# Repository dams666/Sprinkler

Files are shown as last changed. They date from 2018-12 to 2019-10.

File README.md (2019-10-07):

# Sprinkler
Sprinkler est un projet open source d'arrosage intelligent pour son jardin d'intérieur.

Fonctionnalités:
- controle plusieurs vannes
- possède des capteurs d'humidité
- statistiques de consommation d'eau
- détection d'anomalies de fonctionnement (fuites, consommation d'eau excessive...)

Le hardware est disponible sur EADYEDA:
https://easyeda.com/Dams666/sprinkler

Voici la liste des composants (non exhaustive):

http://www.aliexpress.com/item/Free-shipping-6PCS-new-Plastic-electromagnetic-valve-24VDC-12VDC-solenoid-valve-for-drink-water-air-Quick/32402224149.html

http://www.ebay.fr/cln/deofr18/sprinkler/260672069015

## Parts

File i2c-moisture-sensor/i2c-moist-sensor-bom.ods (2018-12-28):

ID | Designator | Value | Qty | FarnellID | Manufacturer | Mfg # | Replacement options
1 | IC1 | Attiny441 | 1 | 2396717 | ATMEL | ATTINY441-SSU | Exact part as specified
2 | D1, D2 | RB521S30T1G | 2 | 2322476 | FAIRCHILD SEMICONDUCTOR | BAT54XV2 | Exact part as specified
3 | TH1 | NCP18XH103F03RB | 1 | 2456122 | MURATA | NCP18XH103F03RB | Exact part as specified
4 | R1 | 10k | 1 | 2379939 | PANASONIC ELECTRONIC COMPONENTS | ERJ3RBD1002V | Any 10k resistor
5 | R2 | 10k 0.5% | 1 | 2379939 | PANASONIC ELECTRONIC COMPONENTS | ERJ3RBD1002V | Exact part as specified
6 | X1 | 16MHz | 1 | 2395958 | MULTICOMP | MCRSD16000F183000RR | Exact part as specified
7 | C1, C2 | 33pF | 2 | 2310585 | MULTICOMP | MC0603N330J500CT | Any 33pF capacitor
8 | R4, R9 | 330R | 2 | 2446656 | MULTICOMP | MCWR06X3300FTL | Any 5% 330R resistor
9 | C3, C6 | 1u 10V | 2 | 2310637 | MULTICOMP | MC0603X105K100CT | Any 1u capacitor
10 | C4, C5 | 1n | 2 | 2310598 | MULTICOMP | MC0603B102K500CT | Any 1n capacitor
11 | R5, R6, R7, R8 | 1M | 4 | 2446602 | MULTICOMP | MCWR06X1004FTL | Any 1M resistor
12 | D3 | KP-1608SURCK | 1 | 2449786 | KINGBRIGHT | KP-1608SURCK | Any 2V Vf 0603 LED
13 | HEATSHRINK |  | 1 |  |  | CB-DWT16-4X/1M-BK

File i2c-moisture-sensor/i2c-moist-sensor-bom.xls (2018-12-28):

Ref | Qnty | Value |  |  | Footprint | Manufacturer | PartNo | Distributor | Comments
C1, C2, | 2 | 33p | 2 | 4 | Capacitors_SMD:C_0603 | MULTICOMP | MC0603N330J500CT | Farnell/2310585 | Can be replaced with 33p 50V capacitors
C3, C6, | 2 | 1u | 2 | 4 | Capacitors_SMD:C_0603 | MULTICOMP | MC0603X105K100CT | Farnell/2310637 | Can be replaced with 1u >=10V capacitors
C4, C5, | 2 | 1n | 2 | 4 | Capacitors_SMD:C_0603 | MULTICOMP | MC0603B102K500CT | Farnell/2310598 | Can be replaced with 1n 50V capacitors
D1, D2, | 2 | BAT54 | 2 | 4 | SMD_Packages:SOD-523 | FAIRCHILD SEMICONDUCTOR | BAT54XV2 | Farnell/2322476 | Exact as specified
D3, | 1 | LED | 2 | 2 | LEDs:LED-0603 | KINGBRIGHT | KP-1608SURCK | Farnell/2449786 | Exact as specified
IC1, | 1 | ATTINY441-SSU | 14 | 14 | Housings_SOIC:SOIC-14_3.9x8.7mm_Pitch1.27mm | ATMEL | ATTINY441-SSU | Farnell/2396717 | Exact as specified
P1, | 1 | CONN_02X03 | 0 | 0 | Pin_Headers:Pin_Header_Straight_2x03 |  |  |  | DNP
R1, | 1 | 10k | 2 | 2 | Resistors_SMD:R_0603 | PANASONIC ELECTRONIC COMPONENTS | ERJ3RBD1002V | Farnell/2379939 | Can be replaced with 10k resistor
R2, | 1 | 10k 0.1% | 2 | 2 | Resistors_SMD:R_0603 | PANASONIC ELECTRONIC COMPONENTS | ERJ3RBD1002V | Farnell/2379939 | Exact as specified
R4, R9, | 2 | 330 | 2 | 4 | Resistors_SMD:R_0603 | MULTICOMP | MCWR06X3300FTL | Farnell/2446656 | Can be replaced with 330R resistor
R5, R8, R7, R6, | 4 | 1M | 2 | 8 | Resistors_SMD:R_0603 | MULTICOMP | MCWR06X1004FTL | Farnell/2446602 | Can be replaced with 1M resistor
TH1, | 1 | NCP18XH103F03RB | 2 | 2 | Resistors_SMD:R_0603 | MURATA | NCP18XH103F03RB | Farnell/2456122 | Exact as specified
X1, | 1 | 16MHz | 2 | 2 | Crystals:Crystal_HC49-SD_SMD | MULTICOMP | MCRSD16000F183000RR | Farnell/2395958 | Exact as specified
 |  |  |  | 52
 |  |  |  | 1.56

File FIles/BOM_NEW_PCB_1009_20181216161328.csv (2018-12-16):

ID | Name | Designator | Footprint | Quantity | Manufacturer Part | Manufacturer | Supplier | Supplier Part | Mounted
1 | ATMEGA328P-PU | U1 | DIP-28_300MIL | 1 | ATMEGA328P-PU | MICROCHIP | LCSC | C33901 | Yes
2 | 10k | R2,R3,R4 | AXIAL-0.3 | 3 | ? |  |  |  | Yes
3 | 100nF | C1 | RAD-0.1 | 1 | ? |  |  |  | Yes
4 | 22pF | C2,C3 | RAD-0.1 | 2 | ? |  |  |  | Yes
5 | 16MHZ | X1 | OSC-49S-1 | 1 | X49SD16MSD2SC | EasyEDA | EasyEDA | C16212 | Yes
6 | 1N4148 | D2 | DO-35 | 1 | ? |  |  |  | Yes
7 | 5MM CONNECTOR | I2C-1,I2C-2,5V-2,5V-1,VALVE1,VALVE2,VALVEM,VALVE3 | 5MM CONNECTOR | 8 | 5MM CONNECTOR |  |  |  | Yes
8 | DS1307+ | U2 | DIP-8 | 1 | DS1307+ | MAXIM | LCSC | C59267 | Yes
9 | 820 | R1,R5 | AXIAL-0.3 | 2 | ? |  |  |  | Yes
10 | BD139 | Q1 | TO-126 | 1 | BD139 | STMicroelectronics | LCSC | C27866 | Yes
11 | 820k | R6,R7 | AXIAL-0.3 | 2 | ? |  |  |  | Yes
12 | WATER FLOW | U3 | CONNECTOR 3P 5MM_2 | 1 | New SchematicLib |  |  |  | Yes
13 | 2N3904 | Q2 | TO-92(TO-92-3) | 1 | 2N3904 | SEMTECH | LCSC | C118538 | Yes
14 | BS-2-1 | B2 | BATTERY-1 | 1 | BS-2-1 | Q&J | LCSC | C70376 | Yes
15 | Quartz 32,7 KHz | X2 | XTAL1X2 | 1 | ? |  |  |  | Yes
16 | CAPACITOR_ELECTROLITIC_470UF | C4 | CAPACITOR_ZLH_10X12.5 | 1 | ? |  |  |  | Yes
17 | TIP120 | Q3,Q5,Q6,Q4,Q7,Q8,Q9 | TO-220_VERTICAL | 7 | ? |  |  |  | Yes
18 | POWER | U4 | CONNECTOR 3P 5MM_2 | 1 | New SchematicLib |  |  |  | Yes
19 | 2.2k | R8,R9,R10,R11,R12,R13,R14 | AXIAL-0.3 | 7 | ? |  |  |  | Yes
20 | MOIST | U5 | CONNECTOR 3P 5MM_2 | 1 | New SchematicLib |  |  |  | Yes
21 | Connector 2.54 2 Pins | U6,U7 | CONNECTOR 2.54 2 PINS | 2 | New SchematicLib |  |  |  | Yes
22 | 5 MM CONNECTER | BUZZER | 5MM CONNECTOR | 1 | 5MM CONNECTOR |  |  |  | Yes
23 | SWITCH-MOMENTARY-2PTH_EZ | S1 | TACTILE-PTH-EZ | 1 | ? |  |  |  | Yes

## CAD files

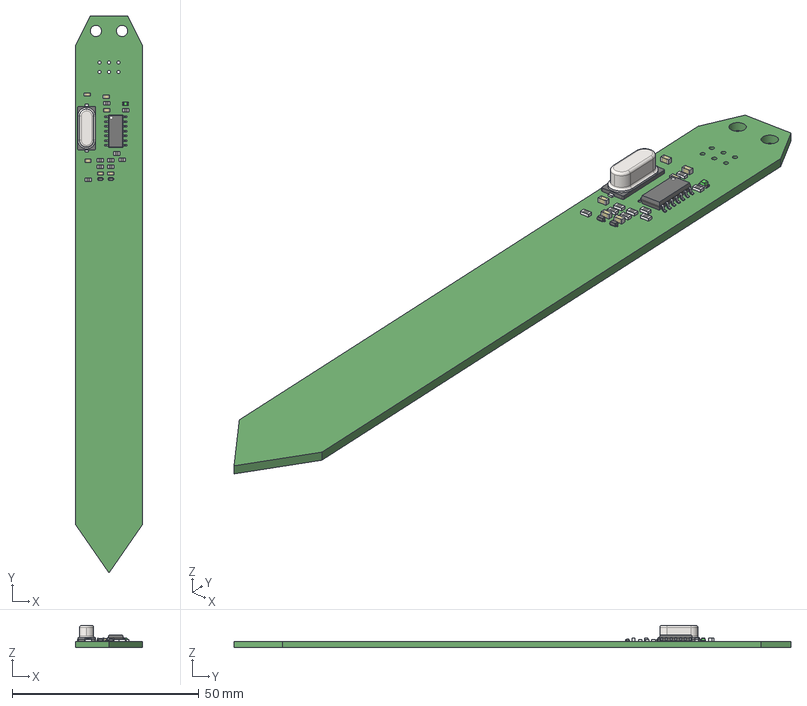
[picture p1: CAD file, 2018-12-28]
i2c-moisture-sensor/i2c-moist-sensor.stp
18.0 x 149.0 x 5.90 mm

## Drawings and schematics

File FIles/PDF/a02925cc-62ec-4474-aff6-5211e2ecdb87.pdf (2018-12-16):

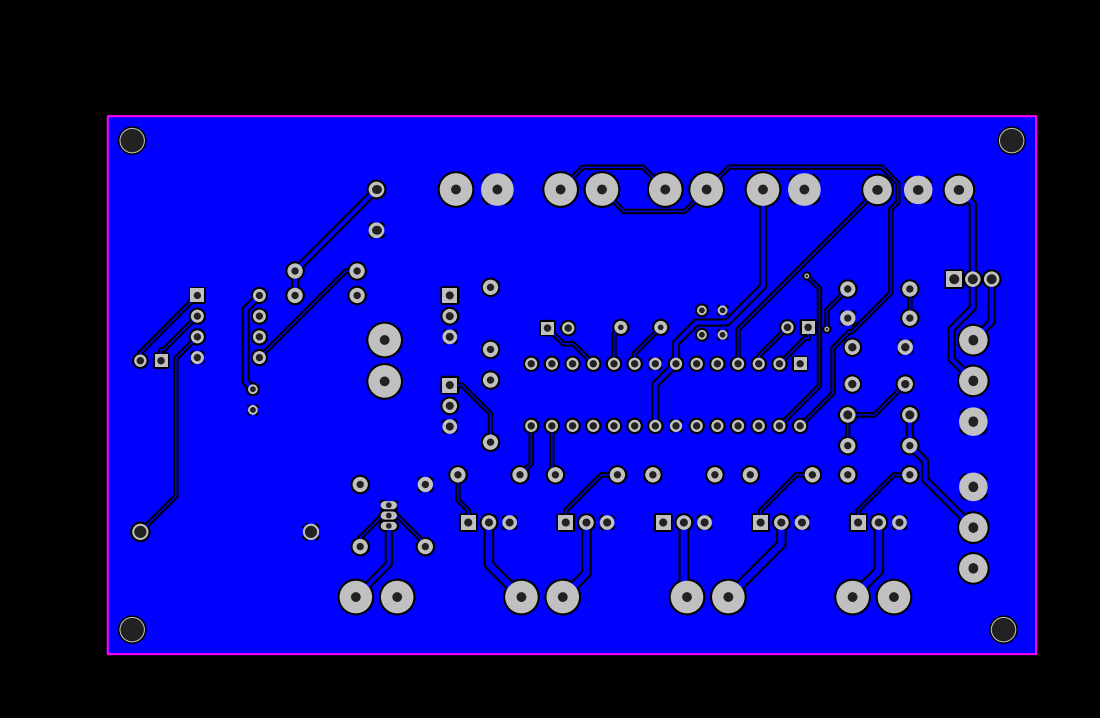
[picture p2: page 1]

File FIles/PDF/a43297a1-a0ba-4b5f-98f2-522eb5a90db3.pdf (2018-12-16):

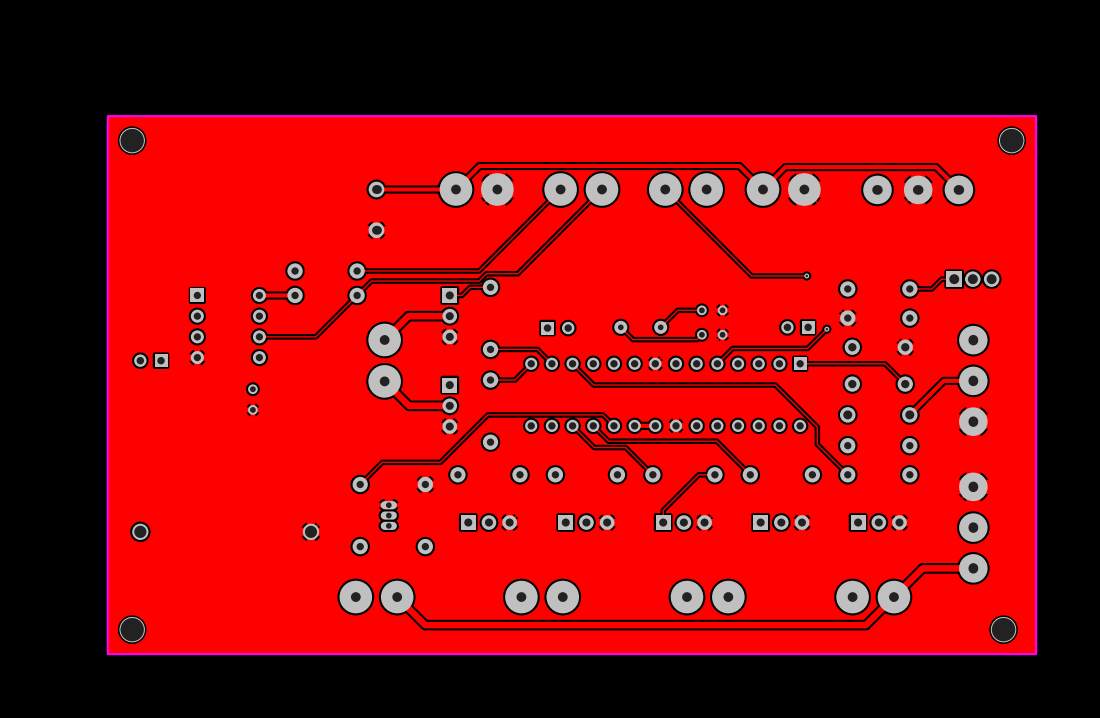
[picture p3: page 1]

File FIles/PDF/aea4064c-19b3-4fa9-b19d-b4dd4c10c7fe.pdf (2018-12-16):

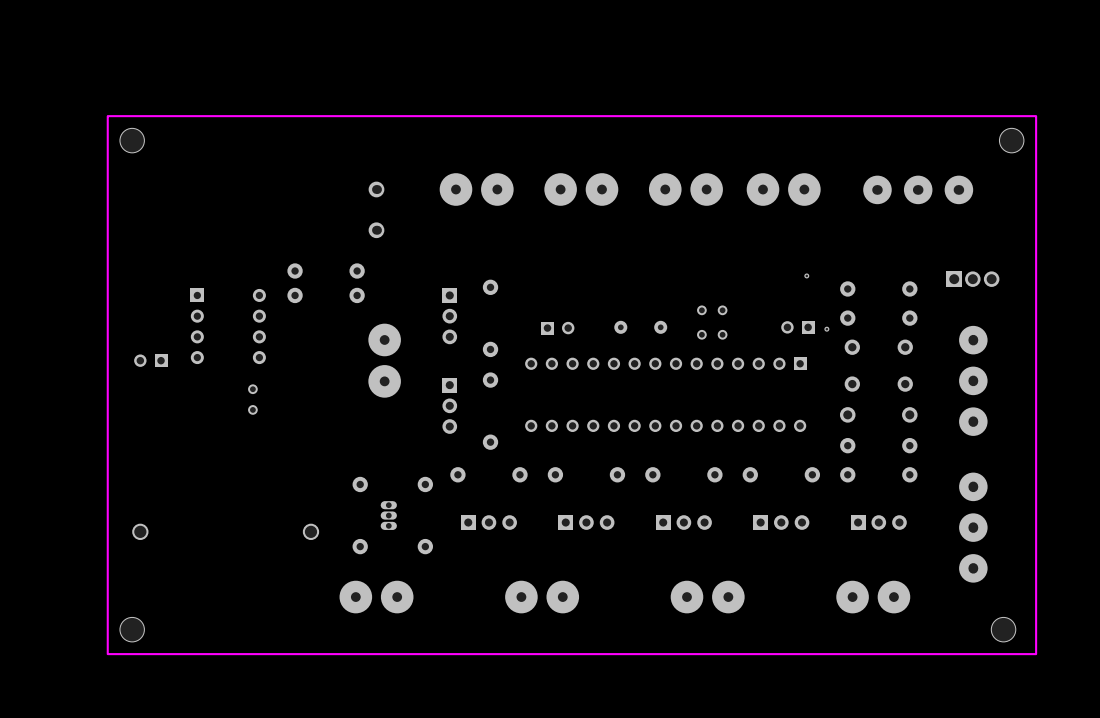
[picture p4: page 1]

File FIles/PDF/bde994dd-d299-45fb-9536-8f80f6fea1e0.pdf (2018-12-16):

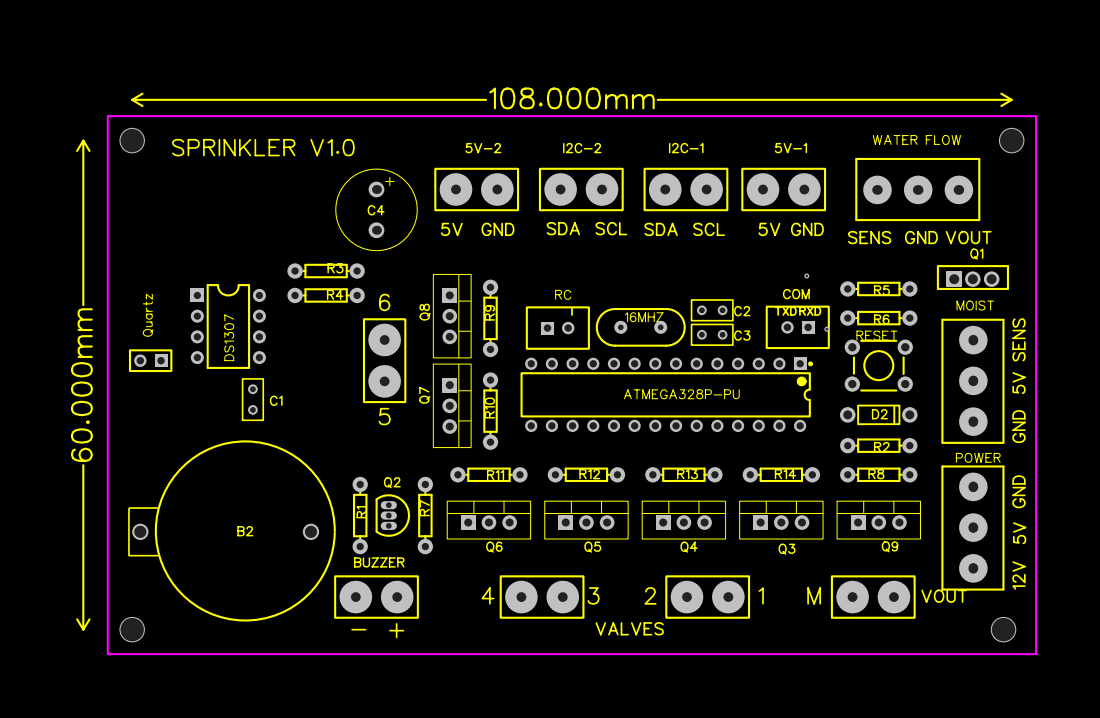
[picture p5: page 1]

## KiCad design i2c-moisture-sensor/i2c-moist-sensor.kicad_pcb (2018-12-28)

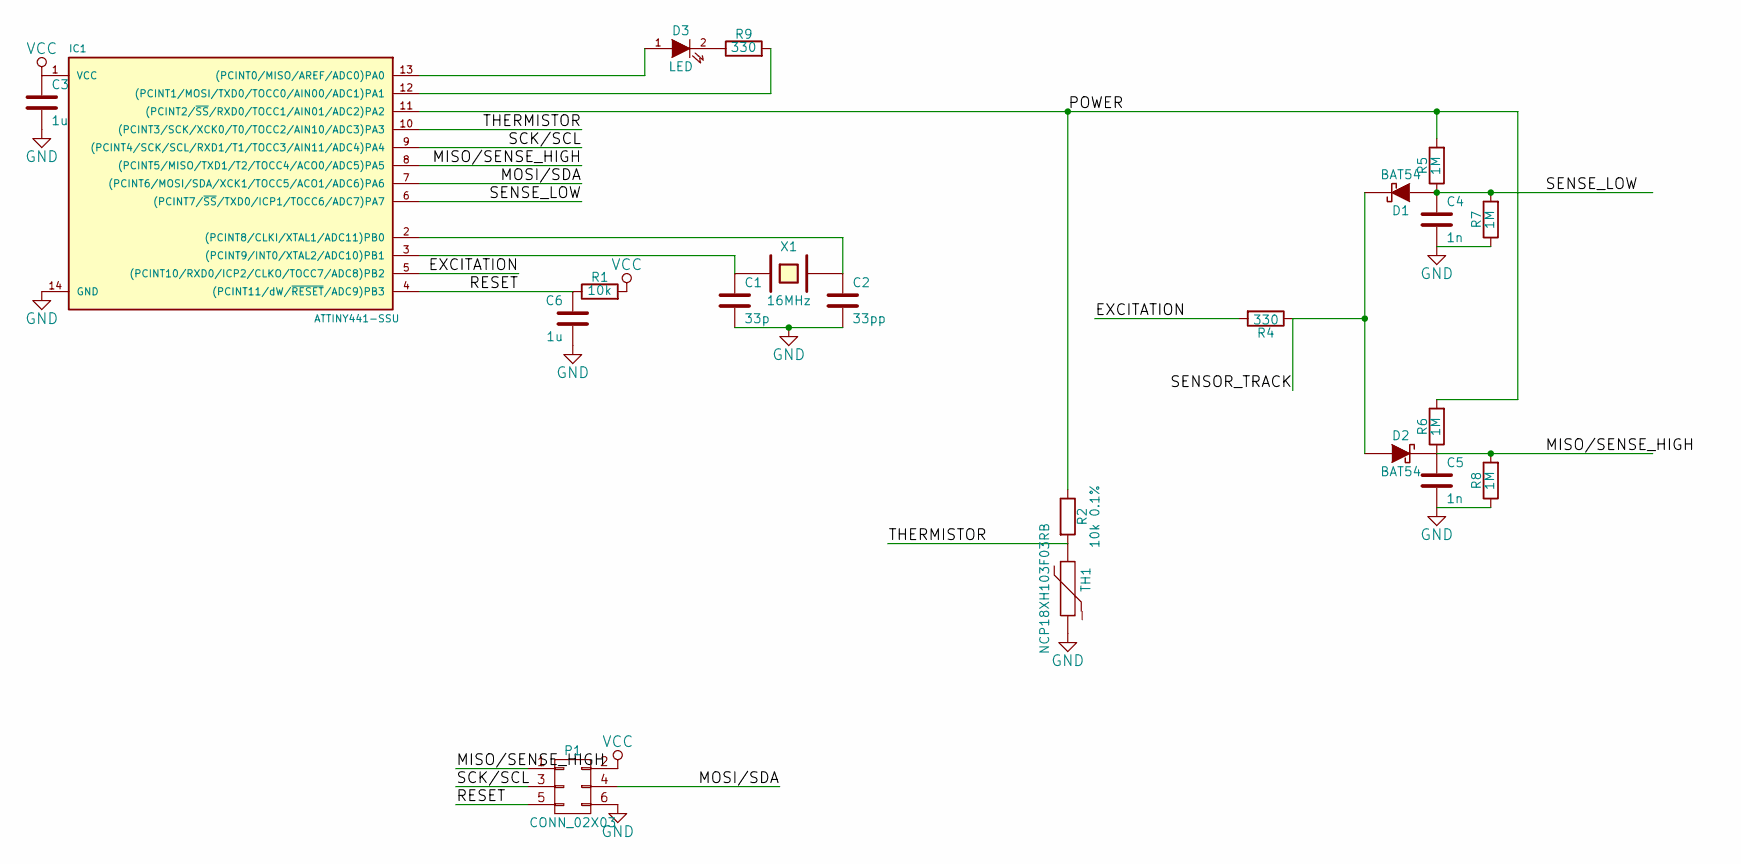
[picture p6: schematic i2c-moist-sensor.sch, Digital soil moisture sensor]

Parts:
C1: 33p; C_0603; PartNo MC0603N330J500CT
C2: 33pp; C_0603; PartNo MC0603N330J500CT
C3, C6: 1u; C_0603; PartNo MC0603X105K100CT
C4, C5: 1n; C_0603; PartNo MC0603B102K500CT
D1, D2: BAT54; SOD-523; PartNo BAT54XV2
D3: LED; LED-0603; PartNo KP-1608SURCK
IC1: ATTINY441-SSU; SOIC-14_3.9x8.7mm_Pitch1.27mm; PartNo ATTINY441-SSU
P1: CONN_02X03; Pin_Header_Straight_2x03
R1: 10k; R_0603; PartNo ERJ3RBD1002V
R2: 10k 0.1%; R_0603; PartNo ERJ3RBD1002V
R4, R9: 330; R_0603; PartNo MCWR06X3300FTL
R5, R6, R7, R8: 1M; R_0603; PartNo MCWR06X1004FTL
TH1: NCP18XH103F03RB; R_0603; PartNo NCP18XH103F03RB
X1: 16MHz; Crystal_HC49-SD_SMD; PartNo MCRSD16000F183000RR

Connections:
/EXCITATION: IC1.5 ((PCINT10/RXD0/ICP2/CLKO/TOCC7/ADC8)PB2), R4.2
/MISO/SENSE_HIGH: C5.1, D2.2 (K), IC1.8 ((PCINT5/MISO/TXD1/T2/TOCC4/ACO0/ADC5)PA5), P1.1, R6.1, R8.2
/MOSI/SDA: IC1.7 ((PCINT6/MOSI/SDA/XCK1/TOCC5/ACO1/ADC6)P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), P1.4
/RESET: C6.1, IC1.4 ((PCINT11/dW/~RESET~/ADC9)PB3), P1.5, R1.1
/SCK/SCL: IC1.9 ((PCINT4/SCK/SCL/RXD1/T1/TOCC3/AIN11/ADC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), P1.3
/SENSE_LOW: C4.1, D1.1 (A), IC1.6 ((PCINT7/~SS~/TXD0/ICP1/TOCC6/ADC7)PA7), R5.1, R7.2
/SENSOR_TRACK: D1.2 (K), D2.1 (A), R4.1
/THERMISTOR: IC1.10 ((PCINT3/SCK/XCK0/T0/TOCC2/AIN10/ADC3)PA3), R2.2, TH1.1
GND: C1.2, C2.2, C3.2, C4.2, C5.2, C6.2, IC1.14 (GND), P1.6, R7.1, R8.1, TH1.2
unnamed: C1.1, IC1.3 ((PCINT9/INT0/XTAL2/ADC10)PB1), X1.1
unnamed: C2.1, IC1.2 ((PCINT8/CLKI/XTAL1/ADC11)PB0), X1.2
unnamed: D3.1 (A), IC1.13 ((PCINT0/MISO/AREF/ADC0)PA0)
unnamed: D3.2 (K), R9.1
unnamed: IC1.11 ((PCINT2/~SS~/RXD0/TOCC1/AIN01/ADC2)PA2), R2.1, R5.2, R6.2
unnamed: IC1.12 ((PCINT1/MOSI/TXD0/TOCC0/AIN00/ADC1)PA1), R9.2
VCC: C3.1, IC1.1 (VCC), P1.2, R1.2

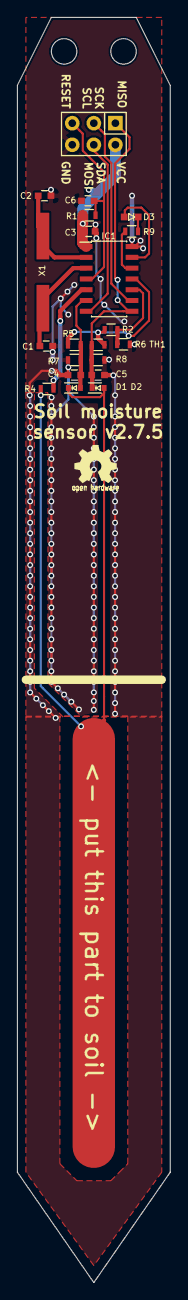
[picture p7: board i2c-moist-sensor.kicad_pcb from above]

Board: 2 copper layers, 18.0 x 149.0 mm, 21 parts (0 on the bottom side), 16 nets.

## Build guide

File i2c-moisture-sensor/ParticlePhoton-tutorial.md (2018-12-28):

Getting sensor to work with Particle Photon
===========================================
by Miriam Cox

As someone completely new to electrical work and to Particle microcontrollers, I hit a few slight hurdles in trying to convert this. For anyone else interested in how I got the sensor working with a Particle Photon, it's pretty simple:

**1) STARTING YOUR PROJECT**
Copy the example code into a "New App" in your Particle.io web IDE. You can name it whatever you'd like. Make sure you ALSO have your Particle Photon microcontroller registered to your Particle account so that you can flash the project onto it.

**2) ADDING A LIBRARY**
Create a new file inside this new app, then name it according to the library you are using (I eventually used Apollon77's code, as suggested by Miceuz) and copy the appropriate code from its git repo into these new files. Don't forget to include the library in your app's main file using the following syntax:
#include "NameOfLibraryFile.h"

_Note: As of this writing, it is also possible to fork this repo and rewrite it for import as a library into your Particle app, but that is a bit more work._

**3) INCLUDES**
In any library or example files you added to your project, strip out "define if/else" statements and their contents, then replace them with the following line (which will add Wire library and device functionality):
**#include "Particle.h"**

Flash your Photon with this app. Assuming you are successful (and assuming you also have the particle software installed on your computer) you can then open up a command line prompt on your computer and enter this command to view the serial monitor output from the Photon:
**particle serial monitor**

**4) SOLDERING**
For prototyping, I unplugged the Photon (which had headers), then popped it onto a breadboard. Then I stripped some jumper wires and soldered them directly to the I2C sensor's SCK/SCL line, VCC line, GND line, and SDA/MOSI line.

Obviously, you need to connect the Photon to your sensor; so to take advantage of the I2C capabilities of the Photon, you'll need to connect the Photon's D1 input to the sensor's SCK/SCL (clock) output, and then connect the Photon's D0 input to the sensor's SDA (data) output on the breadboard. Connect the sensor's VCC line and the Photon's 3V3 (power) input together on the breadboard. Then connect the sensor's GND line and the Photon's GND (ground) lines together on the breadboard.

**VERY IMPORTANT:** You will also need "pull up resistors" on the clock and the data lines; initially, I had NO IDEA what this meant, but, it turns out you'll just connect those lines into the power line using a resistor. All I had to do was grab a resistor and connect one leg of it to the SDA/MOSI-D0 line via the breadboard, then the other leg to the VCC-3V3 (power) line on the breadboard. Then I did the same for the clock, connecting one leg of the resistor to the SCK/SCL-D1 line and the other to the VCC-3V3 line.

_Note: in my case, all I had were 200 ohm resistors, and these at least got my project working. If you don't have any resistors connected, then your particle serial monitor won't even recognize that the I2C sensor is connected. Readings on the web suggest that ideally, you should use somewhere between a 4.7k ohm and 10k ohm resistor for each pull up, to help prevent "drift" on your readings, but someone more electrically inclined than myself could explain/clarify this._

I hope this helps! This sensor is absolutely FANTASTIC, by the way. Very sensitive (which I like), uses capacitive reading (which is much more accurate), and easy to use. Happy DIYing, friends!

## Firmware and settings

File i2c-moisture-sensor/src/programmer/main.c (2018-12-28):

#include "firmware.h"
#include <avr/io.h>
#include <util/delay.h>
#include <avr/pgmspace.h>
#include "usi_i2c_master.h"

#define ISP_OUT   PORTA
#define ISP_IN    PINA
#define ISP_DDR   DDRA
#define ISP_RST   PA0
#define ISP_MOSI  PA6
#define ISP_MISO  PA5
#define ISP_SCK   PA4
#define LED_K PB0 
#define LED_A PB1

#define CLOCK_T_320us   60
#define TIMERVALUE      TCNT0
#define clockInit()  TCCR0B = (1 << CS01) | (1 << CS00);

#define PAGE_SIZE 8 //words

unsigned char sck_sw_delay = 1;

void inline ledOn() {
  DDRB |= _BV(LED_A) | _BV(LED_K); //forward bias the LED
  PORTB &= ~_BV(LED_K);            //flash it to discharge the PN junction capacitance
  PORTB |= _BV(LED_A);  
}

void inline ledOff() {
  DDRB &= ~(_BV(LED_A) | _BV(LED_K)); //make pins inputs
  PORTB &= ~(_BV(LED_A) | _BV(LED_K));//disable pullups
}


static inline void clockWait(uint8_t time) {

    uint8_t i;
    for (i = 0; i < time; i++) {
        uint8_t starttime = TIMERVALUE;
        while ((uint8_t) (TIMERVALUE - starttime) < CLOCK_T_320us) {
        }
    }
}

static inline void ispDelay() {
    uint8_t starttime = TIMERVALUE;
    while ((uint8_t) (TIMERVALUE - starttime) < sck_sw_delay) {
    }
}

unsigned char ispTransmit(unsigned char data) {
    unsigned char rec_byte = 0;
    unsigned char i;
    for (i = 0; i < 8; i++) {
        /* set MSB to MOSI-pin */
        if ((data & 0x80) != 0) {
            ISP_OUT |= (1 << ISP_MOSI); /* MOSI high */
        } else {
            ISP_OUT &= ~(1 << ISP_MOSI); /* MOSI low */
        }
        /* shift to next bit */
        data = data << 1;

        /* receive data */
        rec_byte = rec_byte << 1;
        if ((ISP_IN & (1 << ISP_MISO)) != 0) {
            rec_byte++;
        }

        /* pulse SCK */
        ISP_OUT |= (1 << ISP_SCK); /* SCK high */
        ispDelay();
        ISP_OUT &= ~(1 << ISP_SCK); /* SCK low */
        ispDelay();
    }

    return rec_byte;
}

static inline unsigned char ispEnterProgrammingMode() {
    unsigned char check;
    unsigned char retry = 32;

    while (retry--) {
        ispTransmit(0xAC);
        ispTransmit(0x53);
        check = ispTransmit(0);
        ispTransmit(0);

        if (check == 0x53) {
            return 0;
        }

        /* pulse RST */
        ispDelay();
        ISP_OUT |= (1 << ISP_RST); /* RST high */
        ispDelay();
        ISP_OUT &= ~(1 << ISP_RST); /* RST low */
        ispDelay();
    }
    return 1; /* error: device dosn't answer */
}

static inline void ispConnect() {
    ISP_DDR = 0;
    ISP_OUT = 0;
    /* all ISP pins are inputs before */
    /* now set output pins */
    ISP_DDR |= (1 << ISP_RST) | (1 << ISP_SCK) | (1 << ISP_MOSI);

    /* reset device */
    ISP_OUT &= ~(1 << ISP_RST); /* RST low */
    ISP_OUT &= ~(1 << ISP_SCK); /* SCK low */

    /* positive reset pulse > 2 SCK (target) */
    ispDelay();
    ISP_OUT |= (1 << ISP_RST); /* RST high */
    ispDelay();
    ISP_OUT &= ~(1 << ISP_RST); /* RST low */
}

void ispCommand(unsigned char instruction, unsigned char a1, unsigned char a2, unsigned char a3) {
    ispTransmit(instruction);
    ispTransmit(a1);
    ispTransmit(a2);
    ispTransmit(a3);    
}

static inline unsigned char isPageBoundary(unsigned int i) {
    return i > 0 && 0 == (i + 1) % (PAGE_SIZE);
}

static inline void setFuses(unsigned char low, unsigned char high, unsigned char extended) {
    ispCommand(0xAC, 0xA0, 0x00, low);
    clockWait(30);
    ispCommand(0xAC, 0xA8, 0x00, high);
    clockWait(30);
    ispCommand(0xAC, 0xA4, 0x00, extended);
    clockWait(30);
}

static inline void chipErase() {
    ispCommand(0xAC, 0x80, 00, 00);
    clockWait(30);
}

static inline void flashFirmware() {
    unsigned int i;
    for(i = 0; i < FIRMWARE_WORD_COUNT; i++) {
        if(i % 2) ledOn();
        else ledOff();
        unsigned int word = pgm_read_word(&(firmware[i]));
        ispCommand(0x40, i >> 8, i & 0xFF, word & 0xFF);
        ispCommand(0x48, i >> 8, i & 0xFF, word >> 8);
        if(isPageBoundary(i)) {
            ispCommand(0x4C, i >> 8, i & 0xFF, 0x00);
            clockWait(15);
        }
    }
    
    if(!isPageBoundary(i - 1)) {
        ispCommand(0x4C, (i -1) >> 8, (i - 1) & 0xFF, 0x00);
    }
}

static inline void blink(unsigned int count) {
        int i = 0;
        for(i = 0; i < count; i++) {
                ledOn();
                _delay_ms(50);
                ledOff();
                _delay_ms(50);
        }
}

volatile unsigned char incomming[] = {0x20 << 1 | 0x01, 0x00, 0x00};

static inline char testFirmwareVersionPasses() {
    char getFwVersionCommand[] = {0x20 << 1, 0x07};
    incomming[1] = 0;
    USI_I2C_Master_Start_Transmission(getFwVersionCommand, 2);
    USI_I2C_Master_Start_Transmission(incomming, 2);
    return 0x23 == incomming[1];
}

static inline char testCapacitanceWithinLimits() {
    char readCapacitanceCommand[] = {0x20 << 1, 0x00};
    USI_I2C_Master_Start_Transmission(readCapacitanceCommand, 2);
    incomming[1] = 0;
    incomming[2] = 0;
    _delay_ms(1);
    USI_I2C_Master_Start_Transmission(incomming, 3);
    unsigned int capacitance = ((((unsigned int) incomming[1]) << 8) | incomming[2]);
    return capacitance > 180 && capacitance < 300;
} 

static inline char testTempWithinLimits() {
    char readCapacitanceCommand[] = {0x20 << 1, 0x05};
    USI_I2C_Master_Start_Transmission(readCapacitanceCommand, 2);
    incomming[1] = 0;
    incomming[2] = 0;
    _delay_ms(1);
    USI_I2C_Master_Start_Transmission(incomming, 3);
    unsigned int temp = ((((unsigned int) incomming[1]) << 8) | incomming[2]);
    return temp > 100 && temp < 400;
} 

static inline void blinkError() {
    ledOn();
    _delay_ms(2000);
    ledOff();
}

static inline unsigned char testsPass() {
    return testFirmwareVersionPasses() &&
           testTempWithinLimits() &&
           testCapacitanceWithinLimits();
}

void main(void) {
        clockInit();
        
        while(1) {
                ispConnect();
                
                _delay_ms(100);
                while(ispEnterProgrammingMode()) {
                    ispConnect();
                    _delay_ms(500);
                    ledOn();
                    _delay_ms(500);
                    ledOff();
                }
                
                setFuses(0xAE, 0xDF, 0xF5);
                chipErase();
                flashFirmware();
                ledOff();

                ISP_OUT |= (1 << ISP_RST); //release reset
                _delay_ms(300);
                
                ISP_DDR = 0;
                ISP_OUT = 0;
                
                if(!testsPass()) {
                    blinkError();
                } else {
                    blink(30);
                }
                USICR = 0;
        }
}

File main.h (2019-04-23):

#ifndef __MAIN_H__
#define __MAIN_H__

#include <Arduino.h>

#include <Wire.h>  // Comes with Arduino IDE
// Get the LCD I2C Library here: 
// https://bitbucket.org/fmalpartida/new-liquidcrystal/downloads
// Move any other LCD libraries to another folder or delete them
// See Library "Docs" folder for possible commands etc.
#include <Eepromutil.h>
#include <Gui.h>
#include <ModuleConfig.h>
  
#ifdef WITH_SERIAL
#define DEBUG_PRINT(msg)\
Serial.print((msg));                              
#else
#define DEBUG_PRINT(msg) 
#endif

#ifdef WITH_SERIAL
#define DEBUG_PRINTLN(msg)\
Serial.println((msg));      \
delay(50);                      
#else
#define DEBUG_PRINTLN(msg) 
#endif


#define BUZZER_PIN LED_BUILTIN
#define SLEEPING_DURATION_        600000  // 1h
#define WITH_DS1307
//#undef WITH_DS1307

//------------------------------------
// GUI
//------------------------------------

#define LCD_I2C_ADDR 0x3F
#define RC_PIN 5

//-------------------------------------------------------------------------------------------------------------
// VARIABLES DE LA MACHINE A ETAT
//-------------------------------------------------------------------------------------------------------------

 enum  programState {
    PRGM_STATE_UNDEFINED = 0,
    PRGM_STATE_SHOW_MENU = 1,
    PRGM_STATE_SLEEPING = 2,
    PRGM_STATE_ACTIVATING_MOISTURE_SENSORS = 3,
    PRGM_STATE_READING_MOISTURE_SENSORS = 4,
    PRGM_STATE_INSPECTING_FOR_CHANGES = 5,
    PRGM_STATE_ALERT = 6,
    PRGM_STATE_NB = 7
  };

extern volatile uint8_t             __programState;
extern volatile uint8_t             __programNextState;
/* 
 *  ON définit un byte pour éviter les problèmes d'interférence avec l'interrupt
 *  cf: https://www.arduino.cc/reference/en/language/variables/variable-scope--qualifiers/volatile/
*/

extern volatile unsigned long   __programStateMillis;
extern volatile unsigned long   __actionMillis;
extern volatile unsigned long   __nextActionMillis;

typedef void (*action_t)(void);

extern action_t __array_actions[PRGM_STATE_NB]; 
  /*
  On définit un état spécifique des lors qu'il dure un certain temps
   
   PRGM_STATE_SHOW_MENU : 
   
   après allumage ou reboot de l'arduino après plantage. Les vannes secondaires sont ouvertes puis refermées pour dissiper l'eau 
   qui se serait éventuellement accumulée dans les tuyaux entre la vanne princuppale et la vanne secondaire

   on affiche le menu principal
   
   ETAT(S) PRECEDENT(S) :
   AUCUN
   ETAT(S) SUIVANT(S)   : 
   PRGM_STATE_ACTIVATING_MOISTURE_SENSORS 
   
   PRGM_STATE_ACTIVATING_MOISTURE_SENSORS :
   
   activation de l'ensemble des détecteurs d'humidité. On laisse un court instant passer avant de lire les résultats (cf état PRGM_STATE_READING_MOISTURE_SENSORS)
   
   ETAT(S) PRECEDENT(S) :
   PRGM_STATE_SHOW_MENU
   INSPECTING FOR CHANGES : si toutes les vannes secondaires ont été fermées, on passe en veille
   
   ETAT(S) SUIVANT(S)   : 
   PRGM_STATE_READING_MOISTURE_SENSORS
   
   PRGM_STATE_READING_MOISTURE_SENSORS :
   
   lecture des détecteurs d'humidité
   
   ETAT(S) PRECEDENT(S) : 
   PRGM_STATE_ACTIVATING_MOISTURE_SENSORS
   INSPECTING FOR CHANGES : si une vanne secondaire est ouverte, donc une plante est arrosée
   
   ETAT(S) SUIVANT(S)   : 
   PRGM_STATE_INSPECTING_FOR_CHANGES
   
   PRGM_STATE_INSPECTING_FOR_CHANGES :
   
   inspection des changements de valeur des détecteurs d'humidité, et ouverture / fermeture des vannes
   
   ETAT(S) PRECEDENT(S) : 
   INSPECTING FOR CHANGES : si incrémentation de l'identifiant de vanne secondaire à inspecter
   
   ETAT(S) SUIVANT(S)   : 
   INSPECTING FOR CHANGES : si incrémentation de l'identifiant de vanne secondaire à inspecter
   PRGM_STATE_CLOSING_MAIN_VALVE : si une vanne secondaire doit être fermée, on ferme d'abord la vanne principale et on attend que l'eau ne circule plus
   
   PRGM_STATE_CLOSING_MAIN_VALVE :
   
   avant de fermer une vanne secondaire, on ferme la vanne principale et on attend un instant que l'eau ne circule plus (l'effet de fermeture n'est pas toujours immédiat).
   Comme la fermeture n'est pas immédiate, cela permet de maintenir une pression nulle dans les tuyaux entre la vanne principale et les vannes intermédiaires.
   
   ETAT(S) PRECEDENT(S) : 
   INSPECTING FOR CHANGES
   
   ETAT(S) SUIVANT(S)   : 
   
   */
  void sprinklerInit();
  
  void sprinklerAction();
  
  void setProgramAction(uint8_t state, uint8_t delay_ = 100);
  
  bool isAlertState();

/*
static const char PRGM_STATE_NAME_UNDEFINED[] PROGMEM     = "UNDEFINED";
static const char PRGM_STATE_NAME_INITIALIZING[] PROGMEM  = "INITIALIZING";
static const char PRGM_STATE_NAME_SLEEPING[] PROGMEM      = "SLEEPING";
static const char PRGM_STATE_NAME_ACTIVATING_MOISTURE_SENSORS[] PROGMEM = "ACT MOIST SENS";
static const char PRGM_STATE_NAME_INSPECTING_FOR_CHANGES[] PROGMEM = "READ MOIST SENS";
static const char PRGM_STATE_NAME_ALERT[] PROGMEM = "ALERT";
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

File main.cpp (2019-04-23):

#include "main.h"
#include "menus.h"

#ifdef WITH_LOGGER
#include <SPI.h>
#include <SD.h>
#endif

#include "MOD_moisture_sensors.h"
#include "MOD_water_stats.h"
#include "MOD_valves.h"

#ifdef WITH_DS1307
#include <Wire.h>
#include <TimeLib.h>
#include <DS1307RTC.h>
#endif

//-------------------------------------------------------------------------------------------------------------
// VARIABLES DE LA MACHINE A ETAT
//-------------------------------------------------------------------------------------------------------------

//Variables partagées
volatile uint8_t                __programState;
volatile uint8_t                __programNextState;
volatile unsigned long          __programStateMillis;
volatile unsigned long          __nextActionMillis;
volatile unsigned long          __actionMillis;

action_t                        __array_actions[PRGM_STATE_NB]; 


//-------------------------------------------------------------------------------------------------------------
// VARIABLES TRANSVERSES UTILISEES PAR LES DIFFERENTS ETATS
//-------------------------------------------------------------------------------------------------------------

unsigned long                   __curMillis;

// Communication: etat d'alerte
String                          __msg;

// Configuration générale
chanConf                        __channelConf[MAX_CHANNELS_];

// Canal en cours d'inspection
uint8_t                         __curChannel;

// Modules
MOD_moistureSensors_ *          __MOD_moistureSensors;
MOD_waterStats_ *               __MOD_waterStats;
MOD_valves_ *                   __MOD_valves;

// GUI
GUI *                           __gui;


// menu à afficher
uint8_t                         __curMenu;

//-------------------------------------------------------------------------------------------------------------
// VARIABLES SPECIFIQUES A UN ETAT
//-------------------------------------------------------------------------------------------------------------

// Etat de sommeil: affichage de l'heure
unsigned long                   __nextTimeReadTimeMillis;

// -------------------------------------------------------------------------------------------------

void globalFlowIncPulseCounter()
{
  __MOD_waterStats->execute();
}

void readChannelConfs()
{
  eeprom_read_bytes(  0, (byte*)__channelConf, MAX_CHANNELS_ * sizeof(chanConf));
}

void writeChannelConfs()
{
  eeprom_write_bytes(  0, (const byte*)__channelConf, MAX_CHANNELS_ * sizeof(chanConf));
}

uint8_t getNbChannelsActivated()
{
  uint8_t res = 0;
  for (uint8_t thisPin = 0; thisPin < MAX_CHANNELS_; ++thisPin)
    res += (uint8_t)__channelConf[thisPin].active;
  return res;
}

void setProgramAction(uint8_t state, uint8_t delay_)
{
  if (isAlertState()) return;
    
  __programNextState = state;
  __nextActionMillis = millis() + delay_;
}

bool isAlertState()
{
  return __programState == PRGM_STATE_ALERT || __programNextState == PRGM_STATE_ALERT;
}



static void showMenuAction() 
{
  DEBUG_PRINTLN(F("--- SHOW MENU --- "));
  
  switch (__curMenu) // See which menu item is selected and execute that correspond function
  {    
    case L_MENU_MAIN :
      doMainMenuAction(__gui->displayMenu(MAIN_MENU));
      break;
      
    case L_MENU_STATISTICS :
      doStatisticsMenuAction(__gui->displayMenu(STATISTICS_MENU));
      break;
    
    case L_MENU_CONFIGURE :
      doConfigureMenuAction(__gui->displayMenu(CONFIGURE_MENU));
      break;
  }    
}

static void sleepAction()
{
  // entrée dans l'état de sommeil
  if (__programStateMillis == __actionMillis)
  {
    __MOD_moistureSensors->stop();
    LCD_CLEAR();
    LCD_PRINT(0,3,F("SLEEPING..."));
  }
  
  Button_t button;
  // un bouton a été activé ?
  if ((button = __gui->readPushButton()) != BP_NONE)
  {
    setProgramAction(PRGM_STATE_SHOW_MENU);
    __nextTimeReadTimeMillis = 0;
    return;
  }

  #ifdef WITH_DS1307
  // affichage de l'horloge
  if (__curMillis >= __nextTimeReadTimeMillis)
  { 
      char str[LCD_COLUMNS_ + 1];
    
      tmElements_t tm;
      if (RTC.read(tm))
      {
        sprintf_P(str, PSTR("%02d/%02d/%04d  %02d:%02d"), tm.Day, tm.Month, tm.Year, tm.Hour, tm.Minute);
        LCD_PRINT(0,0,str);
      }
                  
      __nextTimeReadTimeMillis = __curMillis + 60000;
  }
  #endif
  
  // sortie de l'état de sommeil
  if (__curMillis - __programStateMillis >= SLEEPING_DURATION_)
  {
    setProgramAction(PRGM_STATE_ACTIVATING_MOISTURE_SENSORS);
    return;
  }
      
  setProgramAction(PRGM_STATE_SLEEPING, 100);
}
  
static void alertAction()
{
    if (!__MOD_valves->stop()) {
      __msg = F("Main valve KO!");
    }
    __MOD_moistureSensors->stop();
    
    while( __gui->readPushButton() == BP_NONE)
    {      
      digitalWrite(BUZZER_PIN, HIGH);   // turn the LED on (HIGH is the voltage level)
      __gui->displayText(__msg, F("ALERT !"), false);
      delay(1000);
      
      digitalWrite(BUZZER_PIN, LOW);   // turn the LED on (HIGH is the voltage level)
      LCD_CLEAR();
      delay(1000);
    }

     setProgramAction(PRGM_STATE_SHOW_MENU);
}

static void activateMoistSensAction()
{ 
  DEBUG_PRINTLN(F("--- ACTIVATING MOISTURE SENSORS ---"));
  __MOD_moistureSensors->start();

  setProgramAction(PRGM_STATE_READING_MOISTURE_SENSORS, 100);
}

static void readMoistSensAction()
{
  __MOD_moistureSensors->execute();    
  setProgramAction(PRGM_STATE_INSPECTING_FOR_CHANGES); 
}
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

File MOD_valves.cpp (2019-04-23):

#include "main.h"
#include "MOD_valves.h"
#include "MOD_moisture_sensors.h"
#include "MOD_water_stats.h"

  MOD_valves_::MOD_valves_()
  { 
    memset (pins, 0, sizeof(uint8_t) * MAX_CHANNELS_);
    
    if (MAX_CHANNELS_>0) pins[0] = VALVE_1_PIN;    
    if (MAX_CHANNELS_>1) pins[1] = VALVE_2_PIN;
    if (MAX_CHANNELS_>2) pins[2] = VALVE_3_PIN;
    if (MAX_CHANNELS_>3) pins[3] = VALVE_4_PIN;
    if (MAX_CHANNELS_>4) pins[4] = VALVE_5_PIN;
    if (MAX_CHANNELS_>5) pins[5] = VALVE_6_PIN;
   
    pinMode(VALVE_M_PIN, OUTPUT);
    
    for (uint8_t thisPin = 0; thisPin < MAX_CHANNELS_; ++thisPin)
    {
      pinMode(pins[thisPin], OUTPUT);
    }

    stop();
  }

  bool MOD_valves_::stop()
  {
    if (!closeMainValve())
      return false;

    for (uint8_t thisPin = 0; thisPin < MAX_CHANNELS_; ++thisPin)
    {
      state[thisPin] = 0;
      digitalWrite(pins[thisPin], VALVE_OFF); // fermeture de la valve
    }
    return true;
  }

  uint8_t  MOD_valves_::getNbValvesOpened()
  {
    uint8_t res = 0;
    for (uint8_t thisPin = 0; thisPin < MAX_CHANNELS_; ++thisPin)
      res +=state[thisPin];

    return res;
  }
  
  bool MOD_valves_::execute()
  {    
     /**
     * 2 cas de déclenchement:
     * 1) Lancement / fermeture des vannes
     * 2) Détection de reprise suite à l'extinction d'une autre vanne
     */
    if ( ! (__MOD_moistureSensors->hasStateChanged(__curChannel) || hasStateChanged()))
    {
      return false;
    }
             
    if (__MOD_moistureSensors->getState(__curChannel)) // activation du moisture sensor
    {
      if (getNbValvesOpened() < MAX_VALVES_OPENED && !state[__curChannel] )
      {
        DEBUG_PRINT(F(" => OPEN VALVE "));
        DEBUG_PRINTLN(__curChannel);

        char str[LCD_COLUMNS_ + 1];
        sprintf_P(str, PSTR("VALVE %d OPENED"), 1 + __curChannel);

        LCD_CLEAR();
        LCD_PRINT(0,0,str);
    
        digitalWrite(pins[__curChannel], VALVE_ON); // activation de la valve
        state[__curChannel] = 1;

        delay(200);
        openMainValve();

      }
    }
    else {
      // fermeture du moisture sensor

      if (state[__curChannel]) 
      {  
        DEBUG_PRINT(F(" => CLOSE VALVE "));
        DEBUG_PRINTLN(1 + __curChannel);
        
        char str[LCD_COLUMNS_ + 1];
        sprintf_P(str, PSTR("VALVE %d CLOSED"), 1 + __curChannel);

        LCD_PRINT(0,0,str);
              
        if (getNbValvesOpened() == 1)
          closeMainValve();
        
        // fermeture de la vanne secondaire
        digitalWrite(pins[__curChannel], VALVE_OFF);
        state[__curChannel] = 0;
        __MOD_waterStats->saveSessionStats();
        __gui->centerText(F("STATISTICS"));
        __MOD_waterStats->show(1);
        
         delay(1000);
      } 
    }
    return true;
  }  

  bool MOD_valves_::hasStateChanged()
  {
    return state[__curChannel] != __MOD_moistureSensors->getState(__curChannel);
  }
  
  bool MOD_valves_::openMainValve()
  {
     if (!__channelConf[__curChannel].active)
      return false;
      
     __MOD_waterStats->start();

     digitalWrite(VALVE_M_PIN, VALVE_ON); // activation de la valve principale
      stateMain = 1;

     return true;
  }
  
  bool MOD_valves_::closeMainValve()
  {
    
    DEBUG_PRINTLN(F(" => CLOSING MAIN VALVE "));
    digitalWrite(VALVE_M_PIN, VALVE_OFF); // fermeture de la vanne principale

    uint8_t attempts = 0;
    // on laisse le temps a l'eau de s'écouler, et de faire baisser la pression dans les tuyaux
    while(__MOD_waterStats->calcFlow() == WATER_FLOWING) {
      ++attempts;
      if (attempts > 20)
        return false;
      delay(500);
    }
    stateMain = 0
    DEBUG_PRINTLN(F(" WATER STOPPED"));   
    return true;  
  }
 

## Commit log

2015-12-15 Main arduino file
2015-12-19 ajout du détecteur d'écoulement d'eau et des statistiques
2016-01-09 enregistrement des statistiques dans l'EEPROM
2016-01-11 Reecriture totale en C++
    Utilisation de modules écrits en C++
2016-01-23 corrections
    GUI passé en lib externe
    [GUI.cpp, GUI.h, MOD_moisture_sensors.cpp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]
2016-01-23 bugfix interrupt
2016-09-17 logger
    ajout d'un logger de mesures d'humidité
2018-12-01 Adaptation du code sur le nouveau hardware Code non fonctionnel TODO: economiser la place mémoire
2018-12-01 PROGMEM: Enonomie de mémoire
2018-12-01 Bugfix / réduction de la place mémoire (suite)
    [MOD_moisture_sensors.cpp, MOD_valves.cpp, MOD_water_stats.cpp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]
2018-12-02 * Bugfix / réduction de la place mémoire (suite & fin)
    [MOD_moisture_sensors.cpp, MOD_valves.cpp, MOD_water_stats.cpp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]
2018-12-03 bugfix / corrections diverses
    [MOD_valves.cpp, MOD_water_stats.cpp, config.h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]
2018-12-05 SPRINKLER : version fonctionnelle sur arduino UNO
2018-12-05 Actuvation de l'heure
2018-12-08 Gui : gestion des touches 0-9 * # de la telecommande
2018-12-08 Gestion des logs de statistiques de consommation d'eau (beta)
2018-12-09 bugfix Log waterings suite à la mise en place du test
    [MOD_water_stats.cpp, main.cpp, main.h]
2018-12-09 Test: ajout scanner i2c
2018-12-10 Utilisation de la nouvelle classe WaterStatsLogger.cpp
2018-12-10 bugfix: les menus ne font plus d'appels récursifs. Cela résoud les problems de chevauchement heap/stack
    [main.cpp, main.h, test_gui.ino]
2018-12-15 Refactirisation / cleanup / bugfix code
    [MOD_moisture_sensors.cpp, MOD_valves.cpp, MOD_water_stats.cpp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]
2018-12-15 corrections ergonomiques: - affichage de l'heure - affichage des menus
    [main.cpp]
2018-12-16 ajout gerbers / composants
    [BOM_NEW_PCB_1009_20181216161328.csv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]
2018-12-28 Déplacement du module moisture sensor dans les librairies. Maj du programme de logger avec utilisation de la SD cart pour effectuer des mesures d'humidité
2018-12-28 Ajout sonde I2C
    [i2c-moist-sensor-bom.ods, i2c-moist-sensor-bom.xls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]
2019-04-23 Réagencement des fichiers de specification hardware
2019-04-23 refactorisation du code corrections mineures
    [MOD_valves.cpp, main.cpp, main.h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]
2019-04-23 Ajout test valves
